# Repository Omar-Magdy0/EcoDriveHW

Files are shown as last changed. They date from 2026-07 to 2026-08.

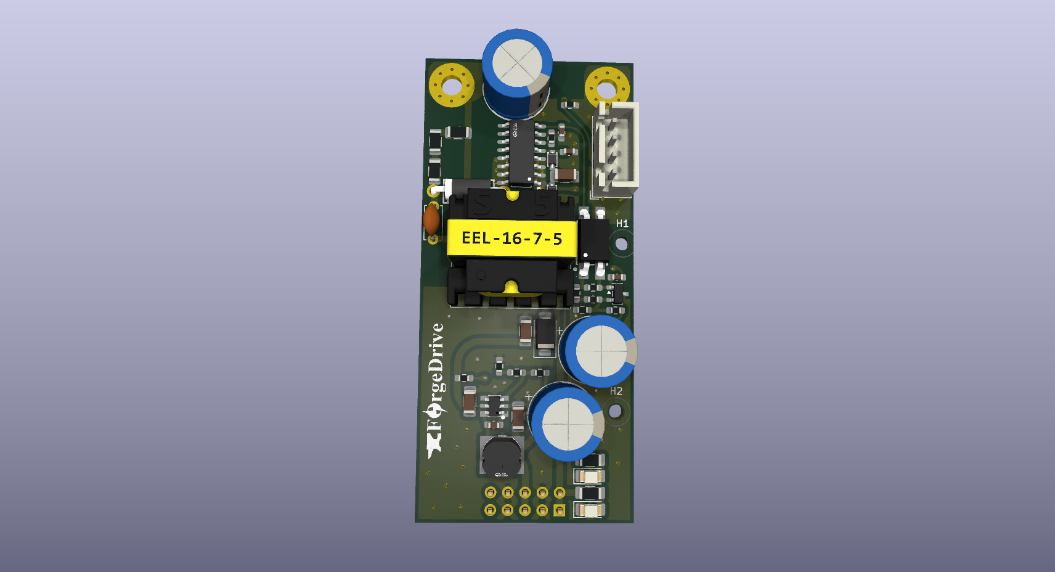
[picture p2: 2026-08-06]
Doc/ForgeX/G0/PSU0.png

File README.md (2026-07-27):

# ForgeDriveHW

_Forged by passionate engineers._

ForgeDrive is an open-source research and development platform for modular, scalable, and industrial-inspired systems.

ForgeDrive is an ecosystem of reusable hardware, firmware, tools, and documentation covering the complete development process—from power electronics and embedded software to simulation, validation, and manufacturing.

The project aims to bridge the gap between academic learning, rapid prototyping, and industrial engineering practices.

---

Vision

ForgeDrive is built around one simple idea:

«Engineering should be understandable, modular, and reusable.»

Every hardware module, software component, and document is designed with long-term maintainability and extensibility in mind.

Whether developing a compact BLDC controller or a complete industrial servo drive, the same design philosophy applies:

- Modular architectures
- Well-defined interfaces
- Thorough documentation
- Reusable building blocks
- Continuous improvement through experimentation

---

##Core Principles

**Modularity**

Each subsystem has a single responsibility.

Examples include:

- Power stages
- Low-voltage distribution
- Communication modules
- Power supplies
- Signal conditioning
- Encoder interfaces
- Processing modules

Modules should be independently testable and reusable across projects.

---

**Scalability**

ForgeDrive is designed to scale across applications.

The same architecture should support:

- Laboratory prototypes
- Educational platforms
- Robotics
- CNC systems
- Industrial automation
- Research projects

---

**Engineering First**

Design decisions are driven by engineering rather than trends.

Topics documented throughout the project include:

- PCB layout
- Power electronics
- Thermal management
- EMC considerations
- Signal integrity
- Embedded software architecture
- Control algorithms
- System reliability

---

**Learning by Building**

ForgeDrive is intended to be as educational as it is practical.

Whenever possible, documentation explains:

- Why a decision was made
- Alternative approaches
- Trade-offs
- Advantages and disadvantages
- Experimental results

The goal is to share engineering knowledge—not only finished hardware.

---

Project Scope

ForgeDrive currently explores technologies including:

Hardware

- PMSM Inverters
- BLDC Controllers
- Three-phase power stages
- PFC converters
- Flyback power supplies
- Low-voltage power distribution
- Encoder interfaces
- Communication modules
- Protection circuitry
- High-speed PCB design

---

Embedded Software

- STM32 Development
- Embedded C/C++
- CMSIS
- Low-Level Drivers
- Real-Time Systems
- Communication Protocols
- Bootloaders
- Firmware Architecture

---

Control

- Field Oriented Control (FOC)
- Space Vector Modulation (SVM)
- Trapezoidal Control
- Current Control
- Position Control
- Speed Control
- Sensorless Algorithms

---

Modeling & Simulation

- MATLAB / Simulink
- Model-Based Design (MBD)
- Plant Modeling
- Controller Design
- System Validation

---

Mechanical

- Enclosures
- Thermal Design
- Mounting Systems
- Mechanical Integration

---

## Documentation

Documentation is considered a first-class component of the project.

Each hardware module includes:

- Board overview
- Bring-up guide
- Revision history
- Manufacturing notes
- Known issues
- Validation results

Shared documentation includes:

- System architecture
- Communication protocols
- Electrical standards
- Design guidelines
- Safety considerations
- Development workflow

---

Hardware revisions are maintained independently while Git preserves complete design history.

---

## Design Philosophy

ForgeDrive emphasizes:

- Single Responsibility Principle (SRP)
- Interface-driven design
- Reusable modules
- Hardware abstraction
- Deterministic behavior
- Debuggability
- Maintainability
- Reliability over unnecessary complexity

---

## Open Source

ForgeDrive is developed in the open.

The repository welcomes:

- Bug reports
- Suggestions
- Design discussions
- Pull requests
- Technical reviews

Constructive engineering feedback is always appreciated.

---

## Roadmap

Some long-term goals include:

- Modular PMSM inverter platform
- Modular PFC stage
- Modular power supplies
- Industrial communication modules
- FPGA acceleration
- Complete documentation
- Hardware validation reports
- Automated testing infrastructure
- Educational design guides

---

## Disclaimer

ForgeDrive contains hardware intended for development, experimentation, and learning.

Many projects involve hazardous voltages, high currents, and high-energy systems.

Always follow appropriate electrical safety practices and verify designs before use in real-world applications.

---

License

This repository is released under the applicable open-source license included in this project.

Please refer to the LICENSE file for details.

---

Acknowledgements

ForgeDrive is built through curiosity, experimentation, continuous learning, and a passion for engineering.

«Forged by passionate engineers.»

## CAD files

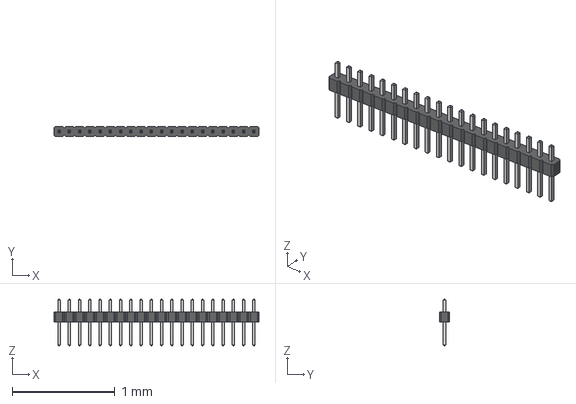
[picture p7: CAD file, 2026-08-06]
ForgeX/BlackDev_G0Basic/LibLocal/header.stp
2.00 x 0.1 x 0.454 mm

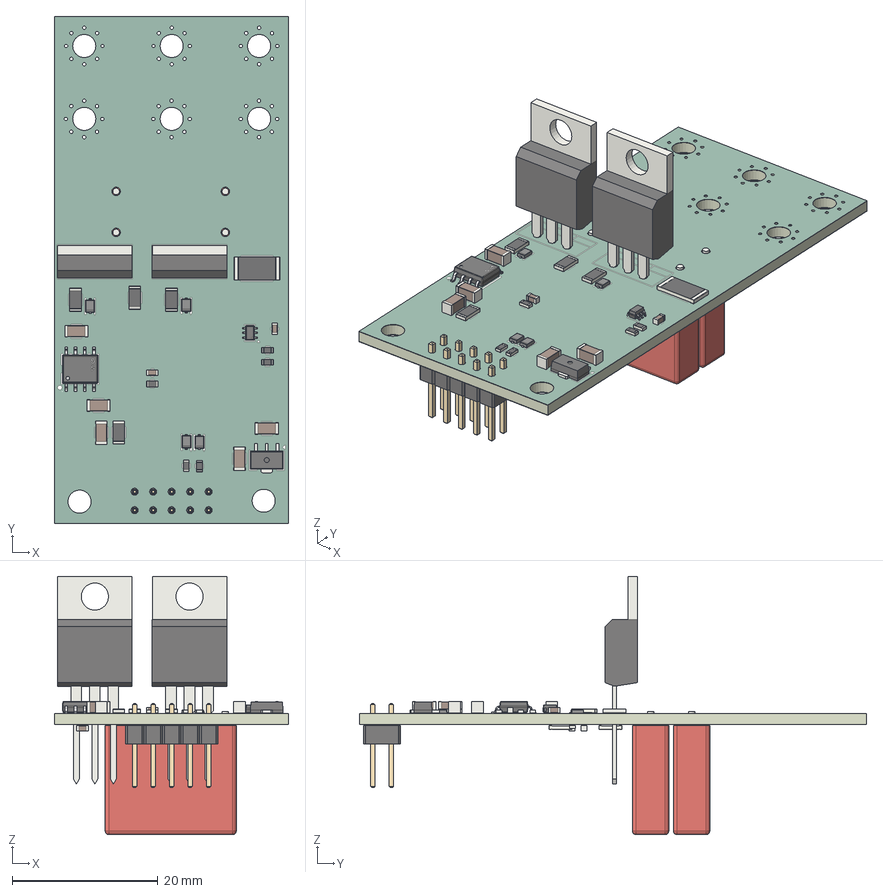
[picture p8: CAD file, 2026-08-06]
ForgeX/HBM_G0VH4C5/revA/Doc/HBM_G0VH4C5.step
32.1 x 69.6 x 35.5 mm
TO-220-3_Vertical x 2
R_0603_1608Metric x 7
C_1206_3216Metric x 5
C_0603_1608Metric x 4
adbeea57-9c39-11ed-93f0-dde97e994e83_part
adbeea58-9c39-11ed-93f0-dde97e994e83_part
adbeea59-9c39-11ed-93f0-dde97e994e83_part
R_2512_6332Metric
R_1206_3216Metric x 6
SO-8_L4.9-W3.9-H1.5-LS5.9-P1.27
SOT-363_SC-70-6
SOD-323_L1.7-W1.3-LS2.5-FD x 4
C_Rect_L180mm_W50mm_P1500mm_FKS3_FKP3 x 2
PinHeader_2x05_P254mm_Vertical
HBM_G0VH4C5_silkscreen x 2
HBM_G0VH4C5_soldermask x 2
HBM_G0VH4C5_PCB

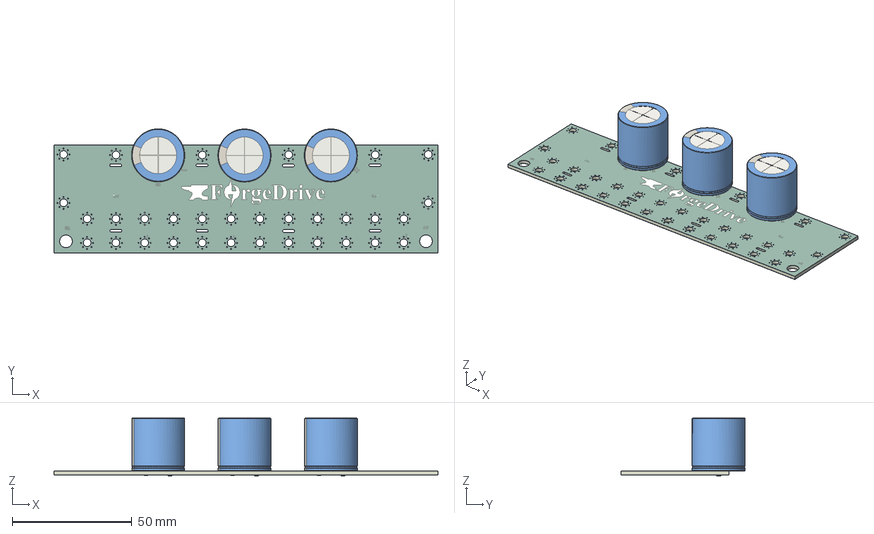
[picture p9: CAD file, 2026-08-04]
ForgeX/PMB_G0S4VH4/revA/Doc/PMB_G0S4VH4.step
160.1 x 51.8 x 24.0 mm
CP_Radial_D220mm_P1000mm_SnapIn x 3
PMB_G0S4VH4_silkscreen
PMB_G0S4VH4_soldermask x 2
PMB_G0S4VH4_PCB

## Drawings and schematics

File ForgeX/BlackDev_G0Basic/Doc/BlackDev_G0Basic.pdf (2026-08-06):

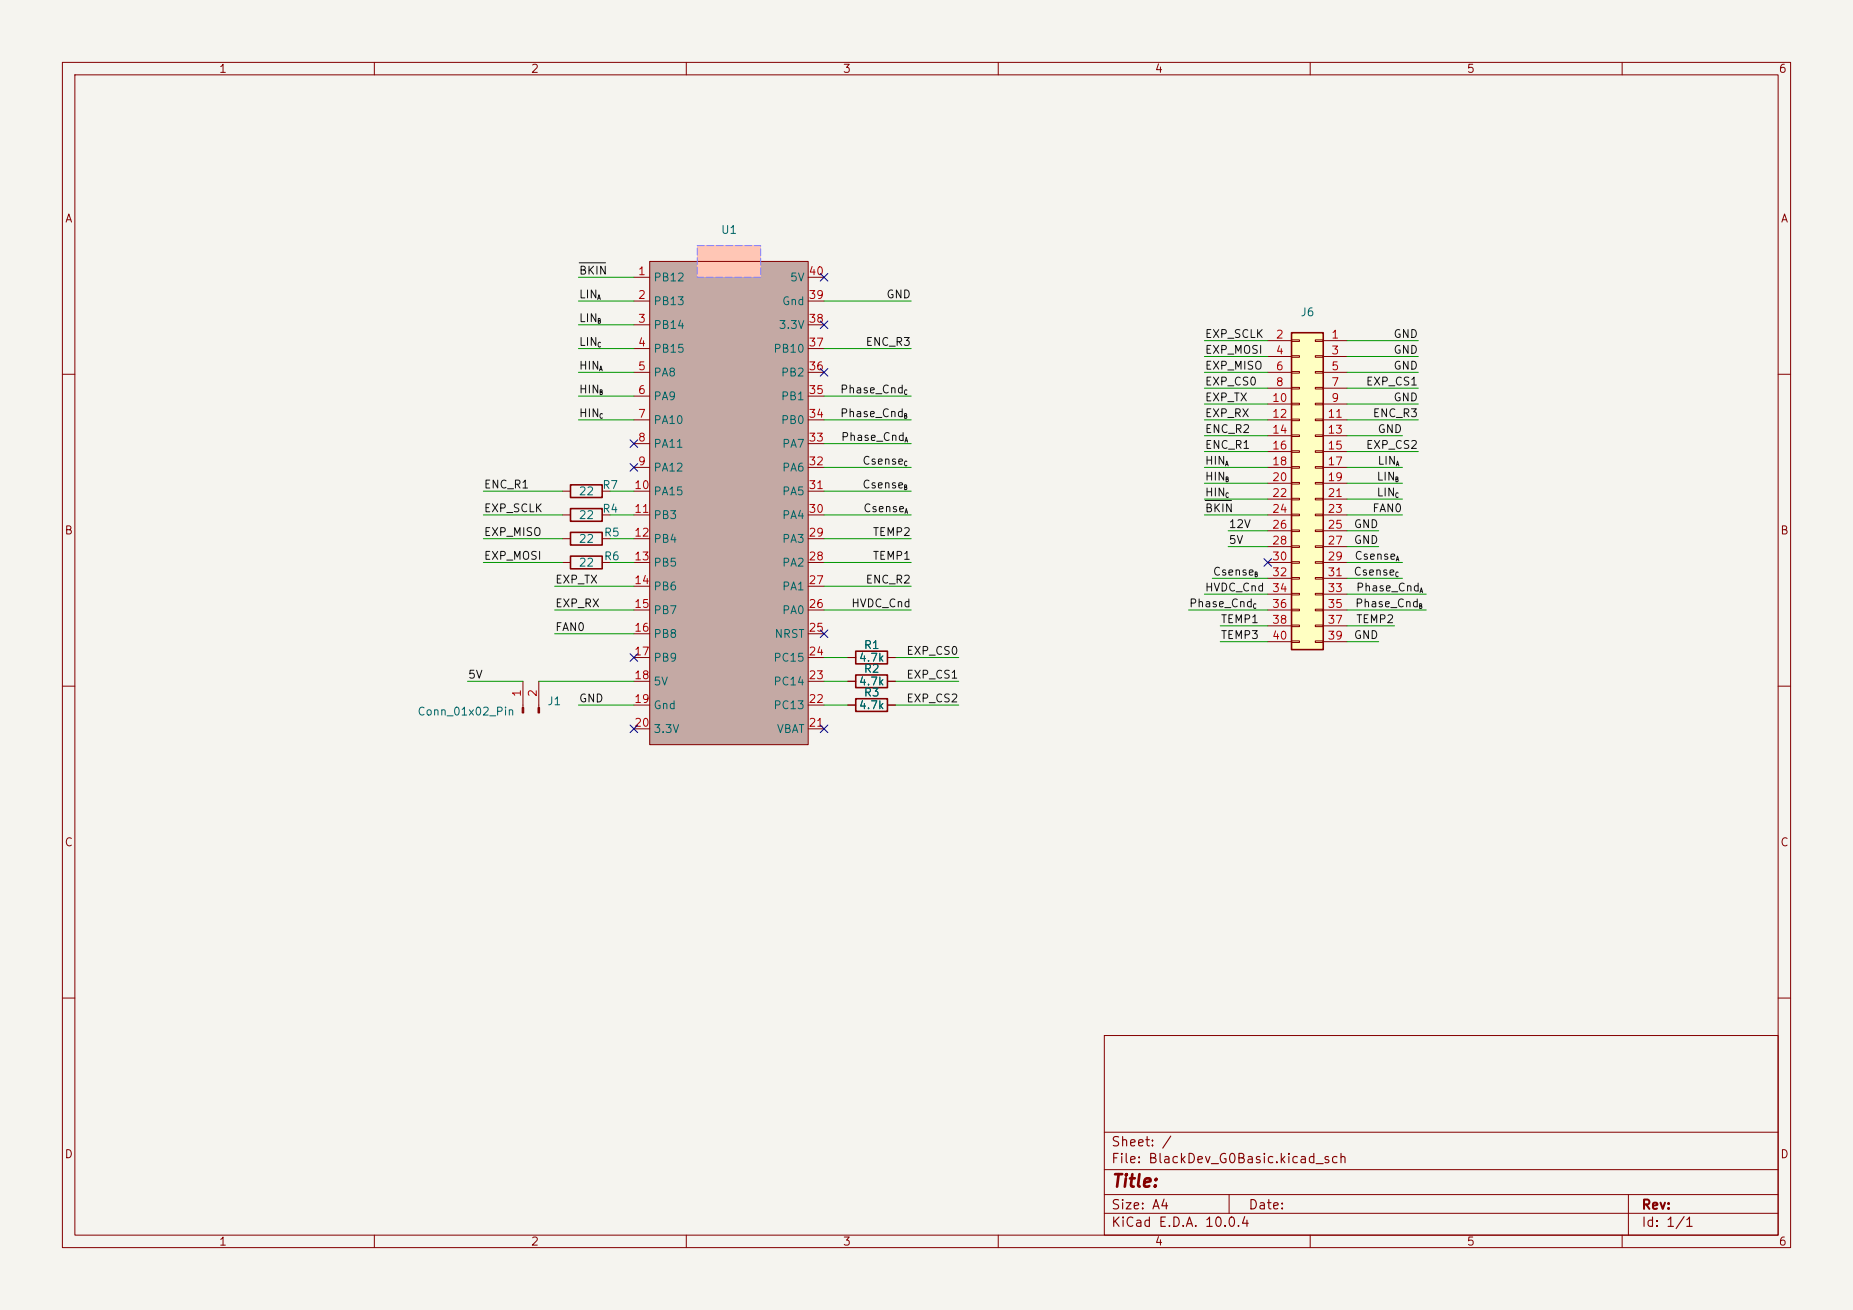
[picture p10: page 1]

Size: A4 | Rev:
KiCad E.D.A. 10.0.4 | Id: 1/1

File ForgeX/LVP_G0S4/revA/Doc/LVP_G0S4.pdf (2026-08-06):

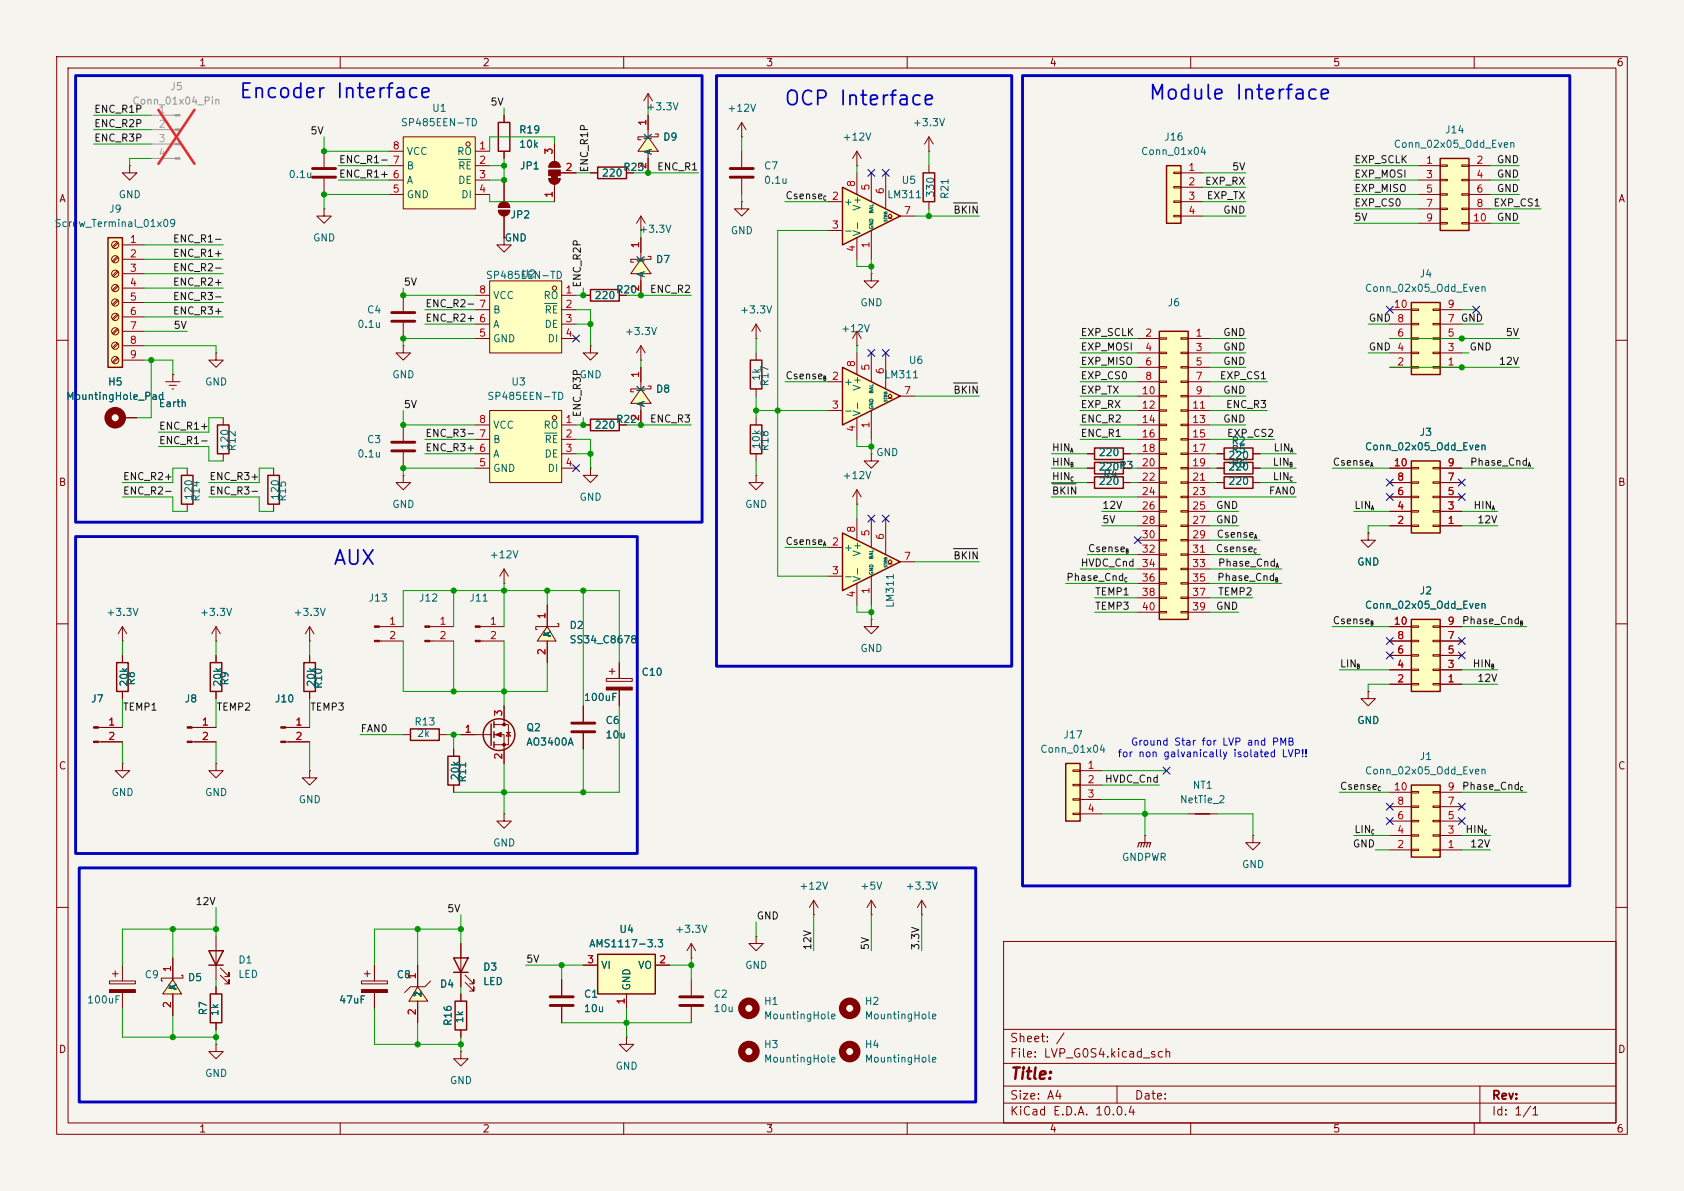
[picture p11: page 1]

for non galvanically isolated LVP!! OCP Interface Encoder Interface

Size: A4 | Rev:
KiCad E.D.A. 10.0.4 | Id: 1/1

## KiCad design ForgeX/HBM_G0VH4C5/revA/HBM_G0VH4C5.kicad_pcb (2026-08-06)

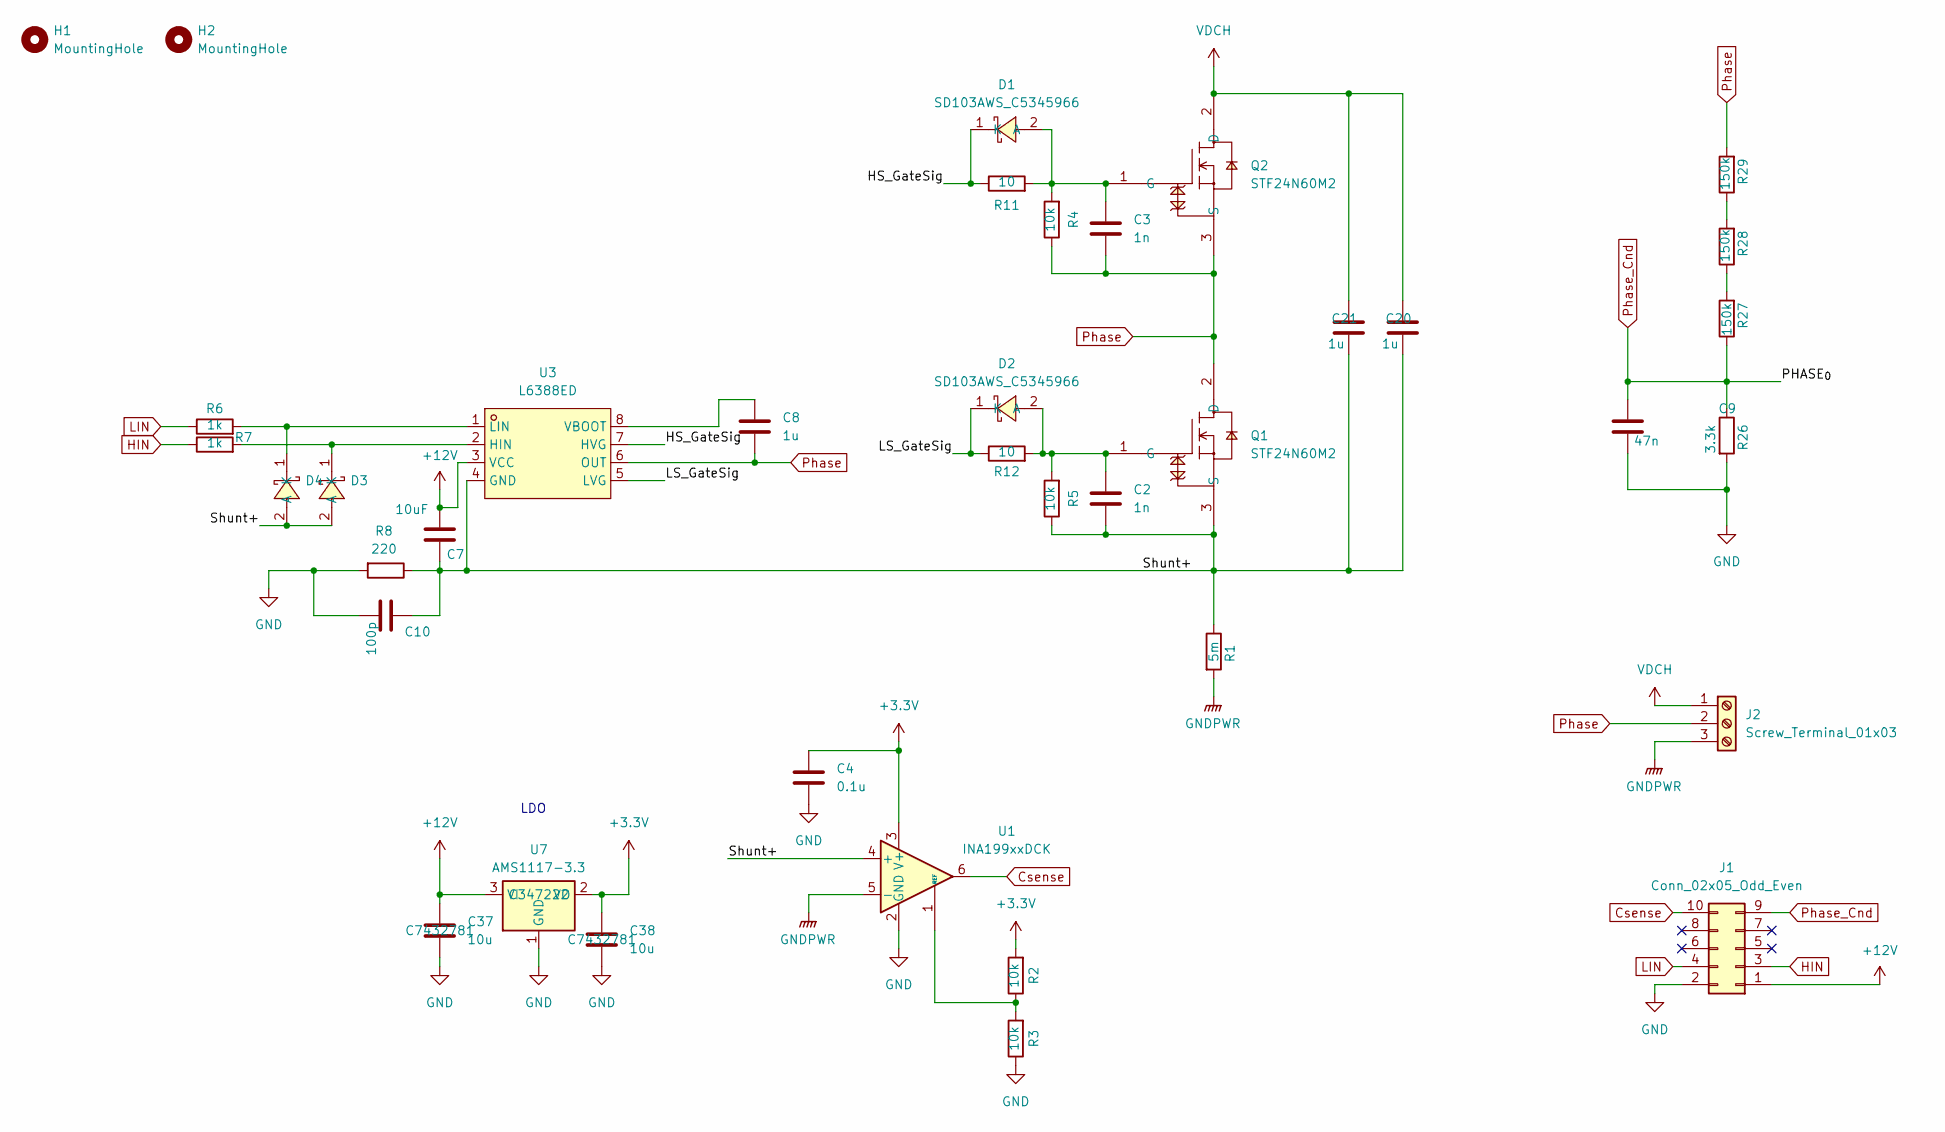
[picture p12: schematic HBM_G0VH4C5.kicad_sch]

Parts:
C2, C3: 1n; C_0603_1608Metric_Pad1.08x0.95mm_HandSolder
C4: 0.1u; C_0603_1608Metric_Pad1.08x0.95mm_HandSolder; LCSC Part C7432781
C7: 10uF; C_1206_3216Metric_Pad1.33x1.80mm_HandSolder
C8: 1u; C_1206_3216Metric_Pad1.33x1.80mm_HandSolder
C9: 47n; C_0603_1608Metric_Pad1.08x0.95mm_HandSolder
C10: 100p; C_1206_3216Metric_Pad1.33x1.80mm_HandSolder
C20, C21: 1u; C_Rect_L18.0mm_W5.0mm_P15.00mm_FKS3_FKP3
C37, C38: 10u; C_1206_3216Metric_Pad1.33x1.80mm_HandSolder; LCSC Part C7432781
D1, D2, D3, D4: SD103AWS_C5345966; SOD-323_L1.7-W1.3-LS2.5-RD; MPN SD103AWS; LCSC Part C5345966
H1, H2: MountingHole; MountingHole_3.2mm_M3_DIN965
J1: Conn_02x05_Odd_Even; PinHeader_2x05_P2.54mm_Vertical
J2: Screw_Terminal_01x03; SPACER_M3_PCONN_2x03
Q1, Q2: STF24N60M2; TO-220-3_Vertical; MPN STF24N60M2; LCSC Part C141847
R1: 5m; R_2512_6332Metric_Pad1.40x3.35mm_HandSolder
R2, R3, R4, R5: 10k; R_0603_1608Metric_Pad0.98x0.95mm_HandSolder
R6, R7: 1k; R_0603_1608Metric_Pad0.98x0.95mm_HandSolder
R8: 220; R_1206_3216Metric_Pad1.30x1.75mm_HandSolder
R11, R12: 10; R_1206_3216Metric_Pad1.30x1.75mm_HandSolder
R26: 3.3k; R_0603_1608Metric_Pad0.98x0.95mm_HandSolder
R27, R28, R29: 150k; R_1206_3216Metric_Pad1.30x1.75mm_HandSolder
U1: INA199xxDCK; SOT-363_SC-70-6
U3: L6388ED; SO-8_L4.9-W3.9-P1.27-LS5.9-BL; MPN L6388ED; LCSC Part C1549313
U7: AMS1117-3.3; SOT-89-3; LCSC Part C347222

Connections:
+3.3V: C4.1, C38.1, R2.2, U1.3 (V+), U7.2 (VO)
+12V: C7.1, C37.1, J1.1, U3.3 (VCC), U7.3 (VI)
/HS_GateSig: D1.1 (K), R11.1, U3.7 (HVG)
/LS_GateSig: D2.1 (K), R12.1, U3.5 (LVG)
/Shunt+: C2.2, C7.2, C10.1, C20.2, C21.2, D3.2 (A), D4.2 (A), Q1.3 (S), R1.1, R5.1, R8.1, U1.4 (+), U3.4 (GND)
Csense: J1.10, U1.6
GND: C4.2, C9.2, C10.2, C37.2, C38.2, J1.2, R3.1, R8.2, R26.2, U1.2 (GND), U7.1 (GND)
GNDPWR: J2.3, R1.2, U1.5 (-)
HIN: J1.3, R7.1
LIN: J1.4, R6.1
unnamed: C3.1, D1.2 (A), Q2.1 (G), R4.2, R11.2
unnamed: C2.1, D2.2 (A), Q1.1 (G), R5.2, R12.2
unnamed: D3.1 (K), R7.2, U3.2 (HIN)
unnamed: D4.1 (K), R6.2, U3.1 (LIN)
unnamed: R27.2, R28.1
unnamed: R28.2, R29.1
unnamed: R2.1, R3.2, U1.1 (REF)
unnamed: C8.1, U3.8 (VBOOT)
Phase: C3.2, C8.2, J2.2, Q1.2 (D), Q2.3 (S), R4.1, R29.2, U3.6 (OUT)
Phase_Cnd: C9.1, J1.9, R26.1, R27.1
VDCH: C20.1, C21.1, J2.1, Q2.2 (D)

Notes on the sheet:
LDO

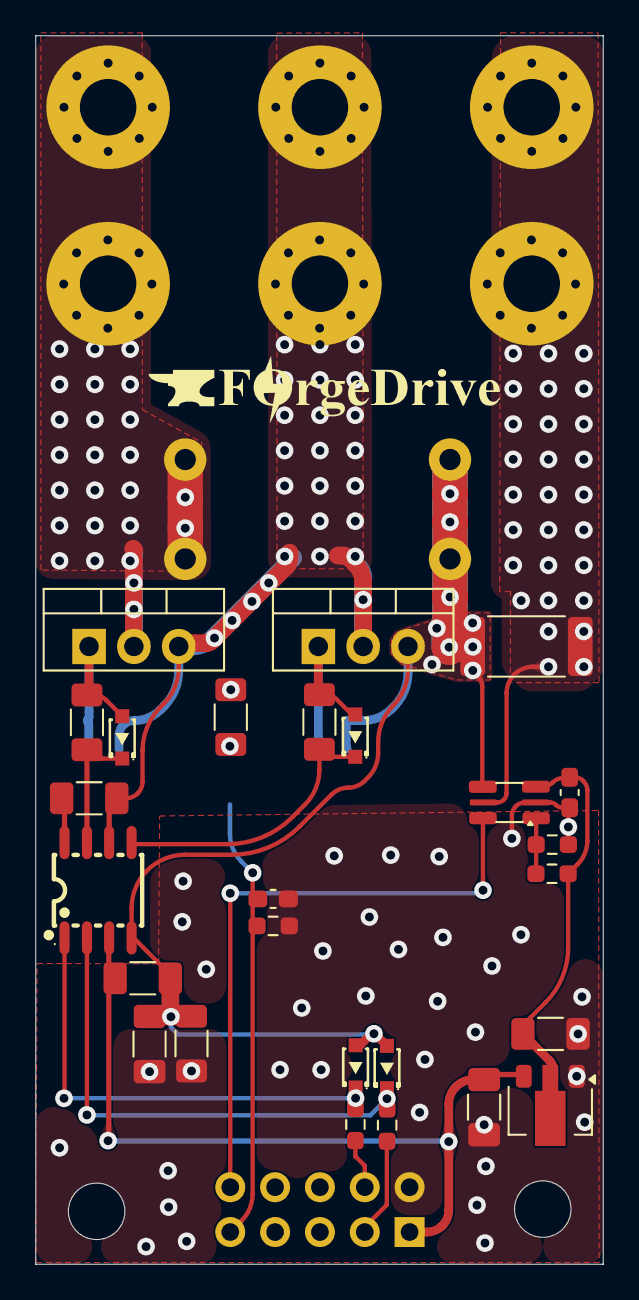
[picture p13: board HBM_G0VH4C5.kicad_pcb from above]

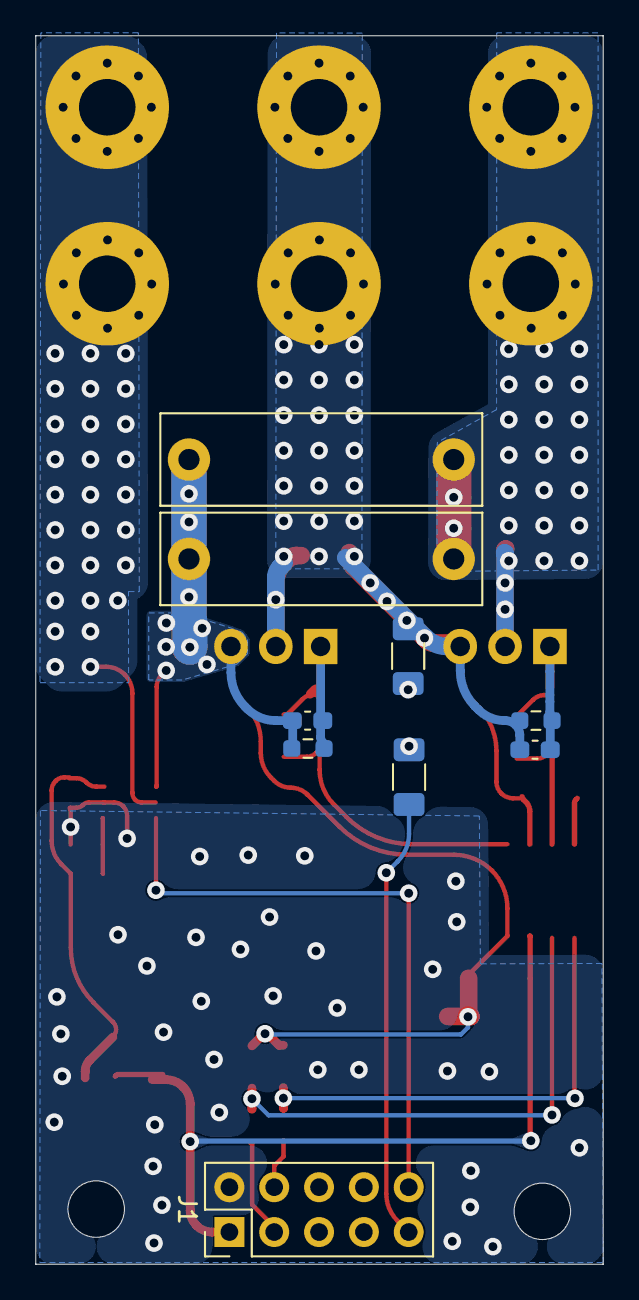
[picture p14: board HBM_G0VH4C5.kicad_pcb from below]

Board: 2 copper layers, 32.2 x 69.6 mm, 38 parts (9 on the bottom side), 21 nets.

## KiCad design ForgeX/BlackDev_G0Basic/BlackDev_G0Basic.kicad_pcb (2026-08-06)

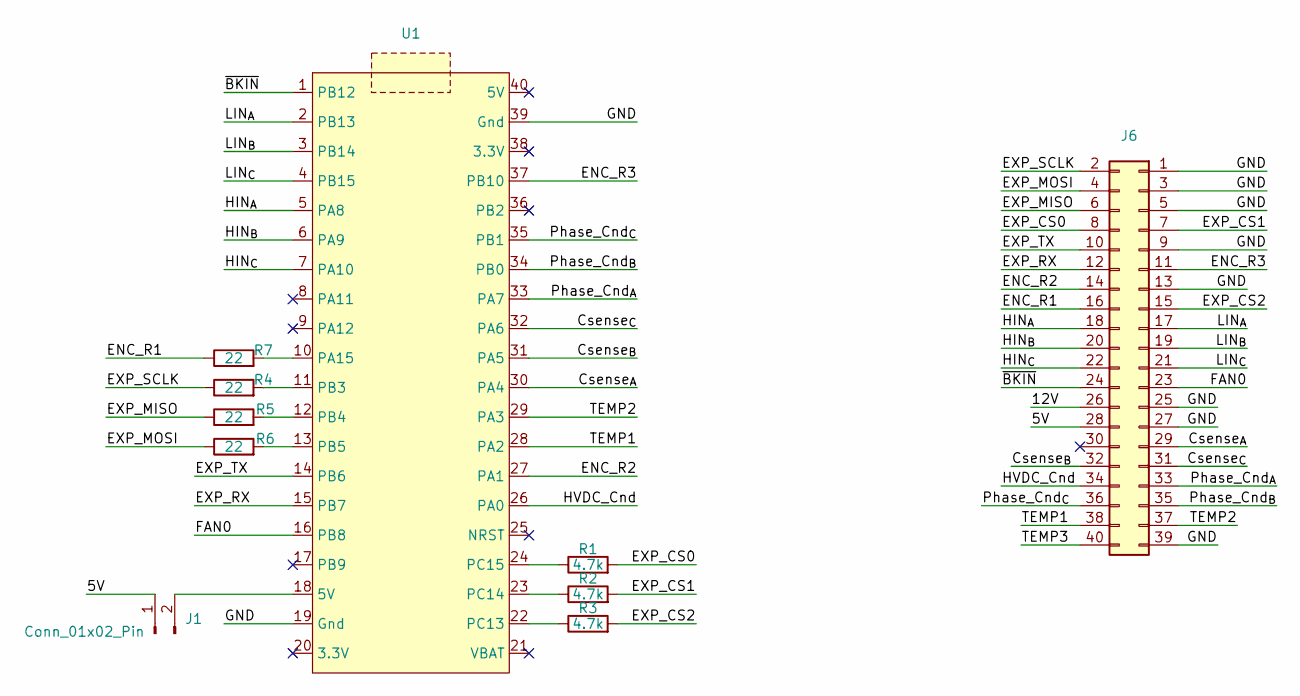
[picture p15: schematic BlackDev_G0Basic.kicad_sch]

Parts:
J1: Conn_01x02_Pin; PinHeader_1x02_P2.54mm_Vertical
J6: Conn_02x20_Odd_Even; PinHeader_2x20_P2.54mm_Vertical
R1, R2, R3: 4.7k; R_0603_1608Metric_Pad0.98x0.95mm_HandSolder
R4, R5, R6, R7: 22; R_0603_1608Metric_Pad0.98x0.95mm_HandSolder
U1: Stm32BlackPill

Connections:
/5V: J1.1, J6.28
/12V: J6.26
/Csense_{A}: J6.29, U1.30 (PA4)
/Csense_{B}: J6.32, U1.31 (PA5)
/Csense_{C}: J6.31, U1.32 (PA6)
/ENC_R1: J6.16, R7.1
/ENC_R2: J6.14, U1.27 (PA1)
/ENC_R3: J6.11, U1.37 (PB10)
/EXP_CS0: J6.8, R1.2
/EXP_CS1: J6.7, R2.2
/EXP_CS2: J6.15, R3.2
/EXP_MISO: J6.6, R5.1
/EXP_MOSI: J6.4, R6.1
/EXP_RX: J6.12, U1.15 (PB7)
/EXP_SCLK: J6.2, R4.1
/EXP_TX: J6.10, U1.14 (PB6)
/FAN0: J6.23, U1.16 (PB8)
/GND: J6.1, J6.3, J6.5, J6.9, J6.13, J6.25, J6.27, J6.39, U1.19 (Gnd), U1.39 (Gnd)
/HIN_{A}: J6.18, U1.5 (PA8)
/HIN_{B}: J6.20, U1.6 (PA9)
/HIN_{C}: J6.22, U1.7 (PA10)
/HVDC_Cnd: J6.34, U1.26 (PA0)
/LIN_{A}: J6.17, U1.2 (PB13)
/LIN_{B}: J6.19, U1.3 (PB14)
/LIN_{C}: J6.21, U1.4 (PB15)
/Phase_Cnd_{A}: J6.33, U1.33 (PA7)
/Phase_Cnd_{B}: J6.35, U1.34 (PB0)
/Phase_Cnd_{C}: J6.36, U1.35 (PB1)
/TEMP1: J6.38, U1.28 (PA2)
/TEMP2: J6.37, U1.29 (PA3)
/TEMP3: J6.40
/~BKIN: J6.24, U1.1 (PB12)
unnamed: J1.2, U1.18 (5V)
unnamed: R7.2, U1.10 (PA15)
unnamed: R4.2, U1.11 (PB3)
unnamed: R5.2, U1.12 (PB4)
unnamed: R6.2, U1.13 (PB5)
unnamed: R3.1, U1.22 (PC13)
unnamed: R2.1, U1.23 (PC14)
unnamed: R1.1, U1.24 (PC15)

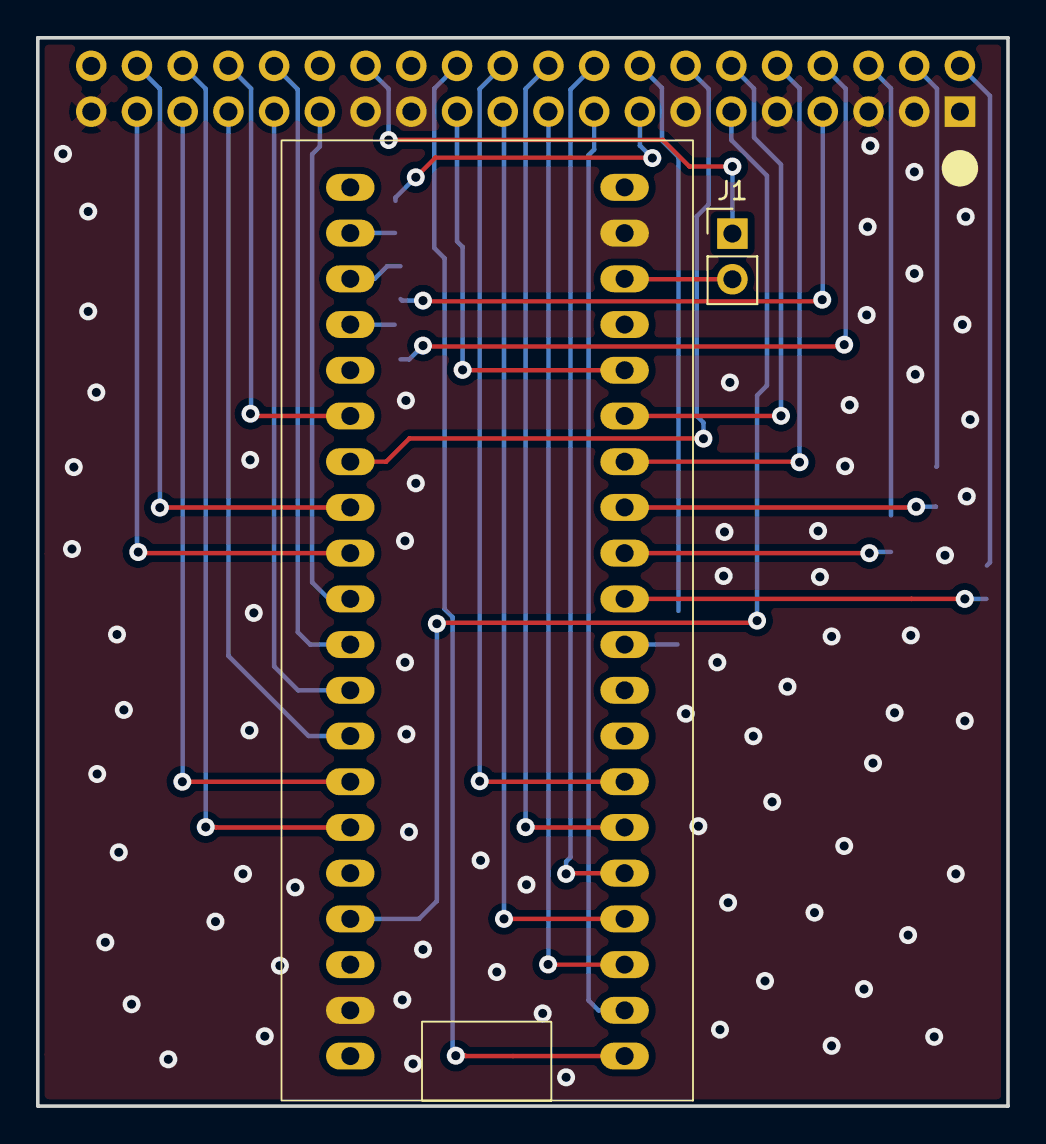
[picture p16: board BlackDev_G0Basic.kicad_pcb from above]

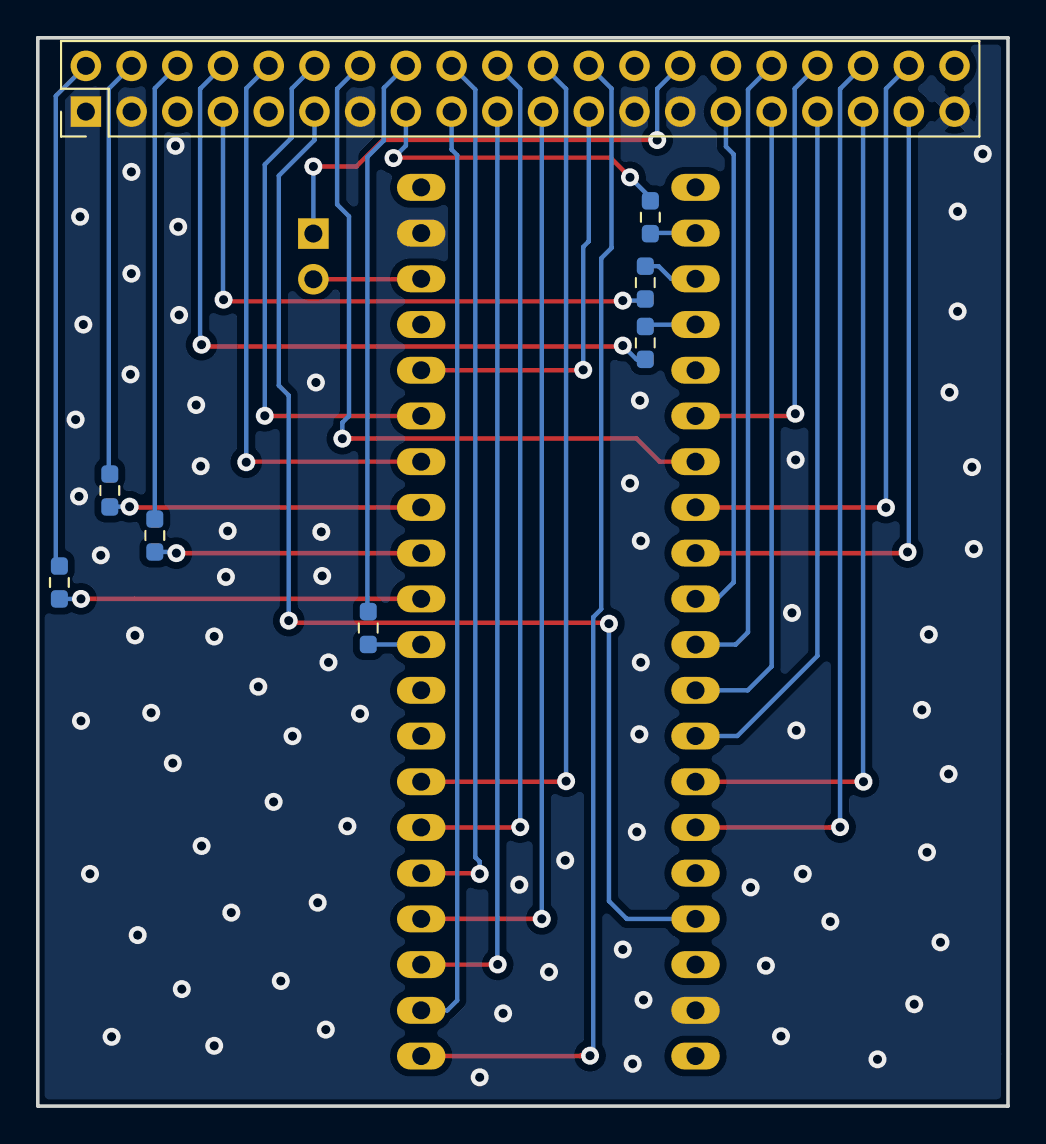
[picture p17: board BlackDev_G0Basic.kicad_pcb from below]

Board: 2 copper layers, 53.9 x 59.4 mm, 10 parts (8 on the bottom side), 38 nets.

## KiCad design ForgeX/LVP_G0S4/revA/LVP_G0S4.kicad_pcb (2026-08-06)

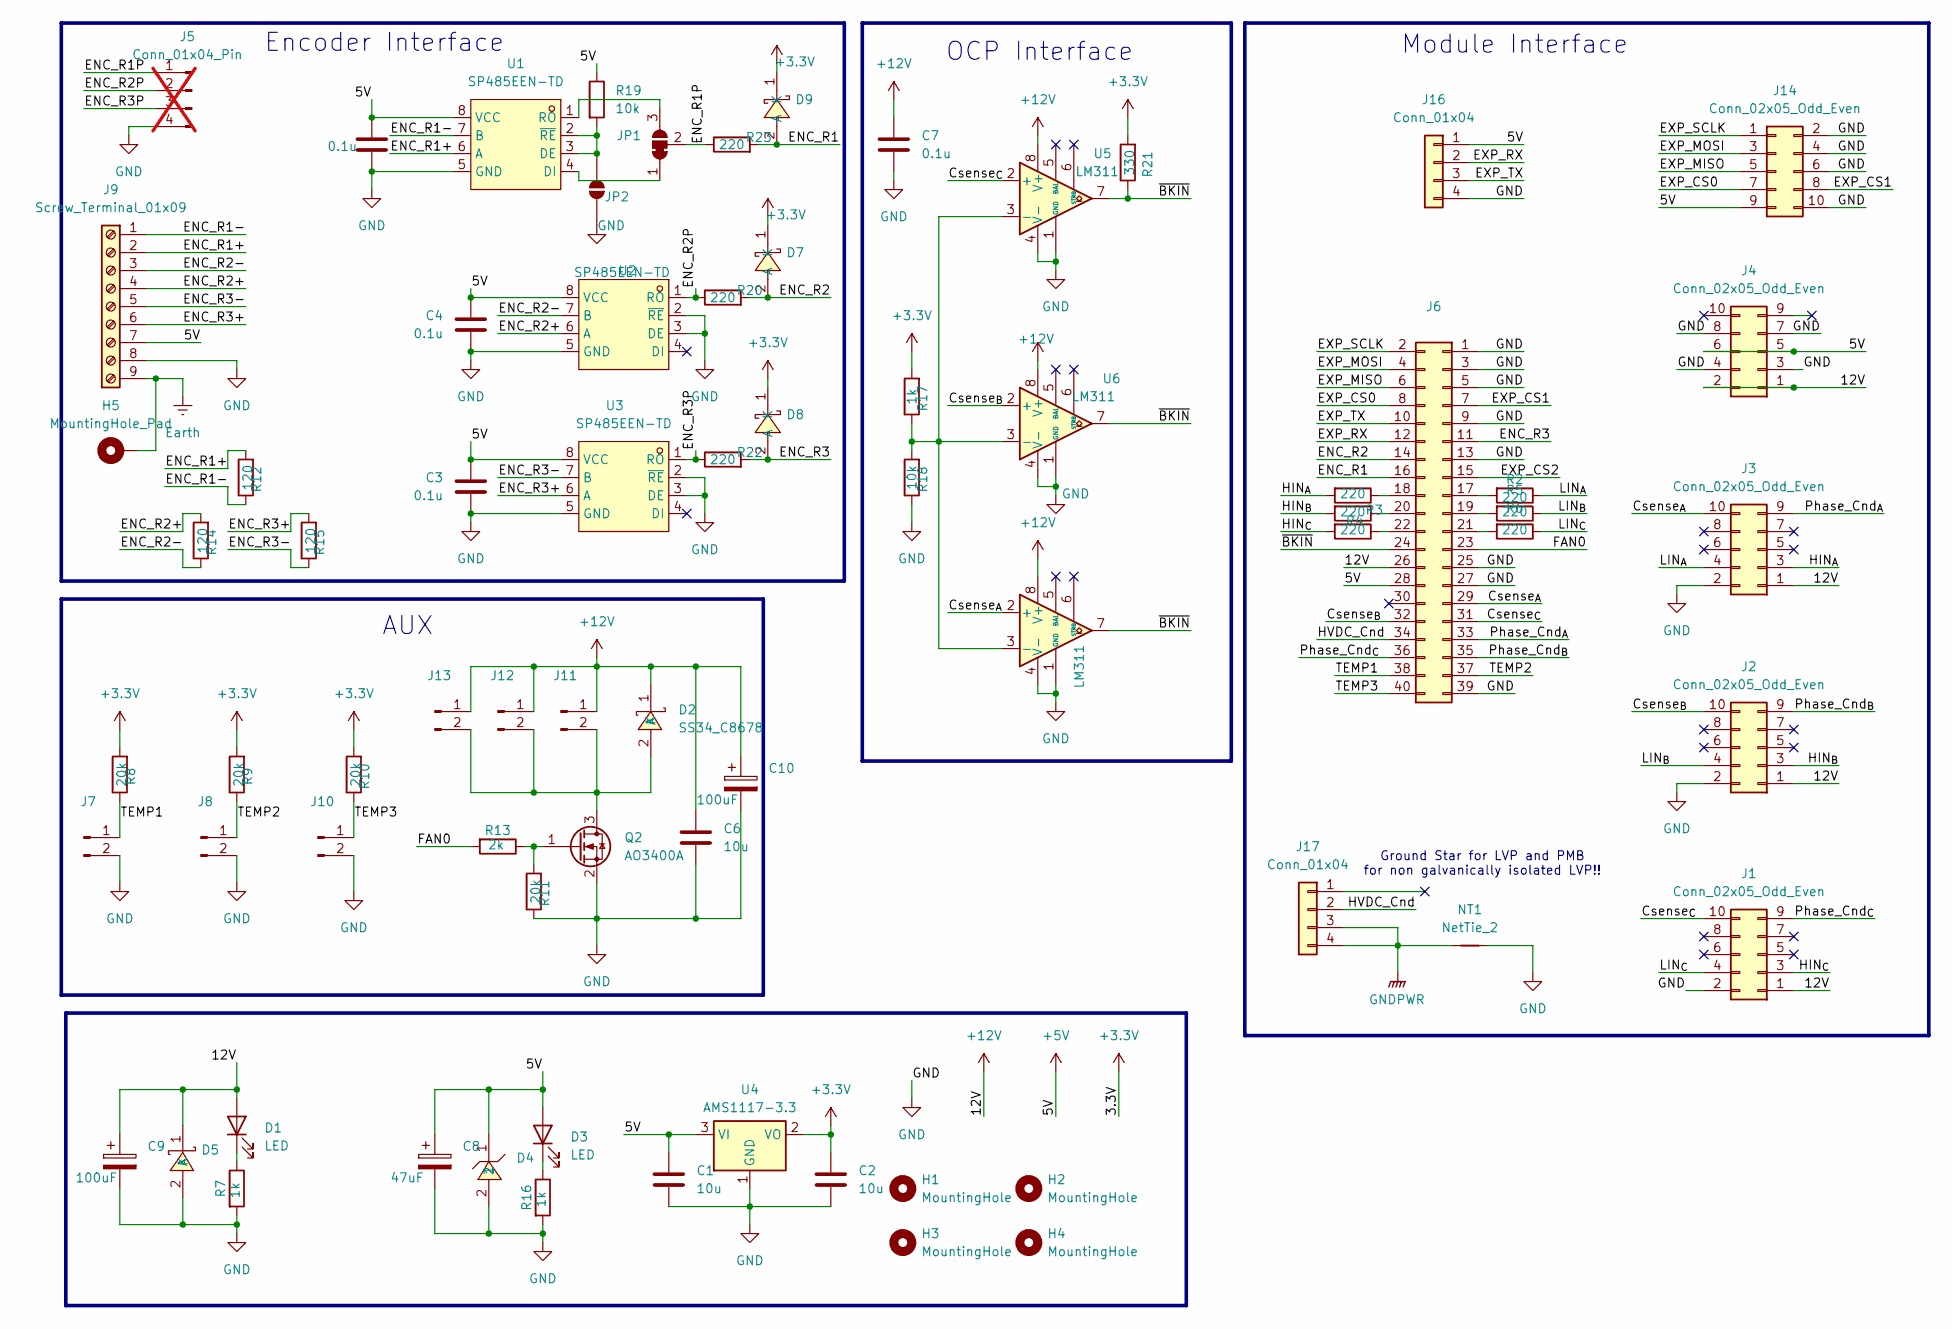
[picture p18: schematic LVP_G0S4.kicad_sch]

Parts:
C1, C2, C6: 10u; C_1206_3216Metric_Pad1.33x1.80mm_HandSolder
C3, C4, C11: 0.1u; C_0603_1608Metric_Pad1.08x0.95mm_HandSolder
C7: 0.1u; C_1206_3216Metric_Pad1.33x1.80mm_HandSolder
C8: 47uF; CP_Elec_5x5.4
C9, C10: 100uF; CP_Elec_8x6.5
D1, D3: LED; LED_0603_1608Metric
D2: SS34_C8678; SMA_L4.3-W2.6-LS5.2-RD; MPN SS34; LCSC Part C8678
D4: SMBJ5.0A_C83333; SMB_L4.6-W3.6-LS5.3-RD; MPN SMBJ5.0A; LCSC Part C83333
D5: SMBJ12A_C151251; SMB_L4.6-W3.6-LS5.3-RD; MPN SMBJ12A; LCSC Part C151251
D7, D8, D9: SD103AWS_C5345966; SOD-323_L1.7-W1.3-LS2.5-RD; MPN SD103AWS; LCSC Part C5345966
H1, H2, H3, H4: MountingHole; MountingHole_3.2mm_M3_DIN965
H5: MountingHole_Pad; MountingHole_3.2mm_M3_Pad_Via
J1, J2, J3, J4: Conn_02x05_Odd_Even; PinSocket_2x05_P2.54mm_Vertical
J5: Conn_01x04_Pin; PinHeader_1x04_P1.27mm_Vertical_SMD_Pin1Right; not fitted
J6: Conn_02x20_Odd_Even; PinSocket_2x20_P2.54mm_Vertical
J7, J8, J10, J11, J12, J13: Conn_01x02_Pin; JST_XH_B2B-XH-A_1x02_P2.50mm_Vertical
J9: Screw_Terminal_01x09; JST_XH_B9B-XH-A_1x09_P2.50mm_Vertical
J14: Conn_02x05_Odd_Even; IDC-Header_2x05_P2.54mm_Vertical
J16: Conn_01x04; PinSocket_1x04_P2.54mm_Vertical
J17: Conn_01x04; JST_XH_B4B-XH-A_1x04_P2.50mm_Vertical
JP1: SolderJumper_3_Bridged12; SolderJumper-3_P1.3mm_Bridged12_RoundedPad1.0x1.5mm
JP2: SolderJumper_2_Open; SolderJumper-2_P1.3mm_Open_TrianglePad1.0x1.5mm
NT1: NetTie_2; ground_tie
Q2: AO3400A; SOT-23
R1, R2, R3, R4, R5, R6, R20, R22, R23: 220; R_0603_1608Metric_Pad0.98x0.95mm_HandSolder
R7, R16, R17: 1k; R_0603_1608Metric_Pad0.98x0.95mm_HandSolder
R8, R9, R10, R11: 20k; R_1206_3216Metric_Pad1.30x1.75mm_HandSolder
R12, R14, R15: 120; R_1206_3216Metric_Pad1.30x1.75mm_HandSolder
R13: 2k; R_1206_3216Metric_Pad1.30x1.75mm_HandSolder
R18, R19: 10k; R_0603_1608Metric_Pad0.98x0.95mm_HandSolder
R21: 330; R_0603_1608Metric_Pad0.98x0.95mm_HandSolder
U1, U2, U3: SP485EEN-TD; SOIC-8_L4.9-W3.9-P1.27-LS6.0-BL; MPN SP485EEN-TD; LCSC Part C41369800
U4: AMS1117-3.3; SOT-89-3
U5, U6, U7: LM311; SOIC-8_3.9x4.9mm_P1.27mm

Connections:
+3.3V: C2.1, D7.1 (K), D8.1 (K), D9.1 (K), R8.2, R9.2, R10.2, R17.2, R21.2, U4.2 (VO)
+5V: C1.1, C3.1, C4.1, C8.1, C11.1, D3.2 (A), D4.1, J4.5, J4.6, J6.28, J9.7, J14.9, J16.1, R19.1, U1.8 (VCC), U2.8 (VCC), U3.8 (VCC), U4.3 (VI)
+12V: C6.1, C7.1, C9.1, C10.1, D1.2 (A), D2.1 (K), D5.1 (K), J1.1, J2.1, J3.1, J4.1, J4.2, J6.26, J11.1, J12.1, J13.1, U5.8 (V+), U6.8 (V+), U7.8 (V+)
/Csense_{A}: J3.10, J6.29, U7.2 (+)
/Csense_{B}: J2.10, J6.32, U6.2 (+)
/Csense_{C}: J1.10, J6.31, U5.2 (+)
/ENC_R1: D9.2 (A), J6.16, R23.2
/ENC_R1+: J9.2, R12.2, U1.6 (A)
/ENC_R1-: J9.1, R12.1, U1.7 (B)
/ENC_R1P: J5.1, JP1.2 (C), R23.1
/ENC_R2: D7.2 (A), J6.14, R20.2
/ENC_R2+: J9.4, R14.2, U2.6 (A)
/ENC_R2-: J9.3, R14.1, U2.7 (B)
/ENC_R2P: J5.2, R20.1, U2.1 (RO)
/ENC_R3: D8.2 (A), J6.11, R22.2
/ENC_R3+: J9.6, R15.2, U3.6 (A)
/ENC_R3-: J9.5, R15.1, U3.7 (B)
/ENC_R3P: J5.3, R22.1, U3.1 (RO)
/EXP_CS0: J6.8, J14.7
/EXP_CS1: J6.7, J14.8
/EXP_CS2: J6.15
/EXP_MISO: J6.6, J14.5
/EXP_MOSI: J6.4, J14.3
/EXP_RX: J6.12, J16.2
/EXP_SCLK: J6.2, J14.1
/EXP_TX: J6.10, J16.3
/FAN0: J6.23, R13.2
/HIN_{A}: J3.3, R1.2
/HIN_{B}: J2.3, R3.2
/HIN_{C}: J1.3, R4.2
/HVDC_Cnd: J6.34, J17.2
/LIN_{A}: J3.4, R2.1
/LIN_{B}: J2.4, R5.1
/LIN_{C}: J1.4, R6.1
/Phase_Cnd_{A}: J3.9, J6.33
/Phase_Cnd_{B}: J2.9, J6.35
/Phase_Cnd_{C}: J1.9, J6.36
/TEMP1: J6.38, J7.1, R8.1
/TEMP2: J6.37, J8.1, R9.1
/TEMP3: J6.40, J10.1, R10.1
/~BKIN: J6.24, R21.1, U5.7, U6.7, U7.7
Earth: H5.1 (1_1), J9.9
GND: C1.2, C2.2, C3.2, C4.2, C6.2, C7.2, C8.2, C9.2, C10.2, C11.2, D4.2, D5.2 (A), J1.2, J2.2, J3.2, J4.3, J4.4, J4.7, J4.8, J5.4, J6.1, J6.3, J6.5, J6.9, J6.13, J6.25, J6.27, J6.39, J7.2, J8.2, J9.8, J10.2, J14.2, J14.4, J14.6, J14.10, J16.4, JP2.2 (B), NT1.2, Q2.2 (S), R7.2, R11.1, R16.2, R18.1, U1.5 (GND), U2.2 (~RE), U2.3 (DE), U2.5 (GND), U3.2 (~RE), U3.3 (DE), U3.5 (GND), U4.1 (GND), U5.1 (GND), U5.4 (V-), U6.1 (GND), U6.4 (V-), U7.1 (GND), U7.4 (V-)
GNDPWR: J17.3, J17.4, NT1.1
unnamed: D1.1 (K), R7.1
unnamed: D2.2 (A), J11.2, J12.2, J13.2, Q2.3 (D)
unnamed: D3.1 (K), R16.1
unnamed: J6.17, R2.2
unnamed: J6.18, R1.1
unnamed: J6.19, R5.2
unnamed: J6.20, R3.1
unnamed: J6.21, R6.2
unnamed: J6.22, R4.1
unnamed: JP1.1 (A), U1.4 (DI)
unnamed: JP1.3 (B), U1.1 (RO)
unnamed: JP2.1 (A), R19.2, U1.2 (~RE), U1.3 (DE)
unnamed: Q2.1 (G), R11.2, R13.1
unnamed: R17.1, R18.2, U5.3 (-), U6.3 (-), U7.3 (-)

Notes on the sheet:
OCP Interface
Ground Star for LVP and PMB for non galvanically isolated LVP!!
AUX
Encoder Interface
Module Interface

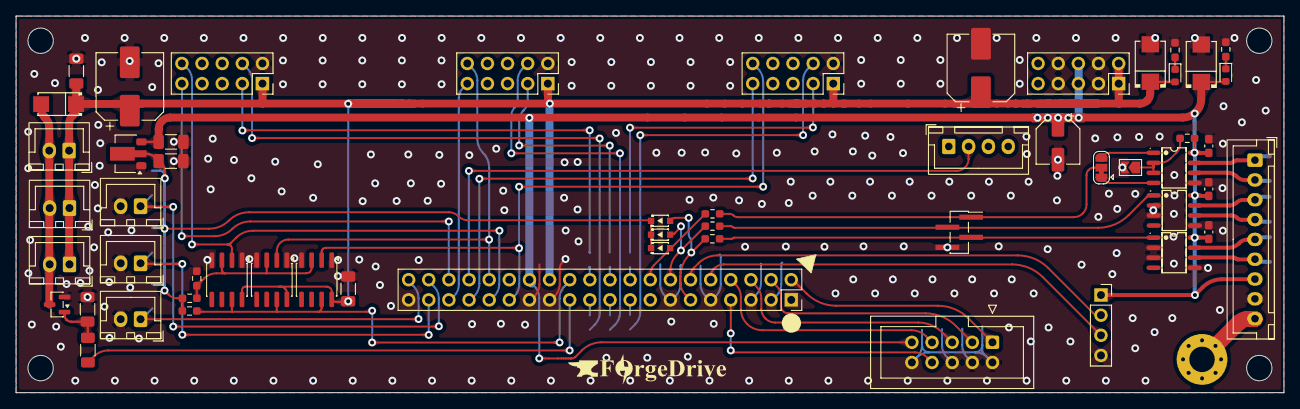
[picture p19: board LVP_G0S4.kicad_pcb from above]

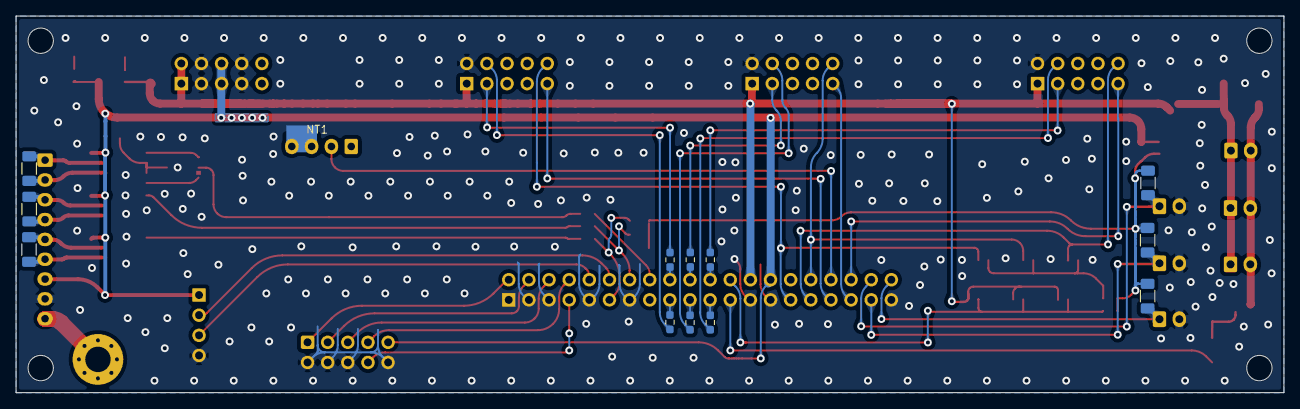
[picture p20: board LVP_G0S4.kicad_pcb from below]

Board: 2 copper layers, 159.9 x 47.5 mm, 73 parts (13 on the bottom side), 57 nets.

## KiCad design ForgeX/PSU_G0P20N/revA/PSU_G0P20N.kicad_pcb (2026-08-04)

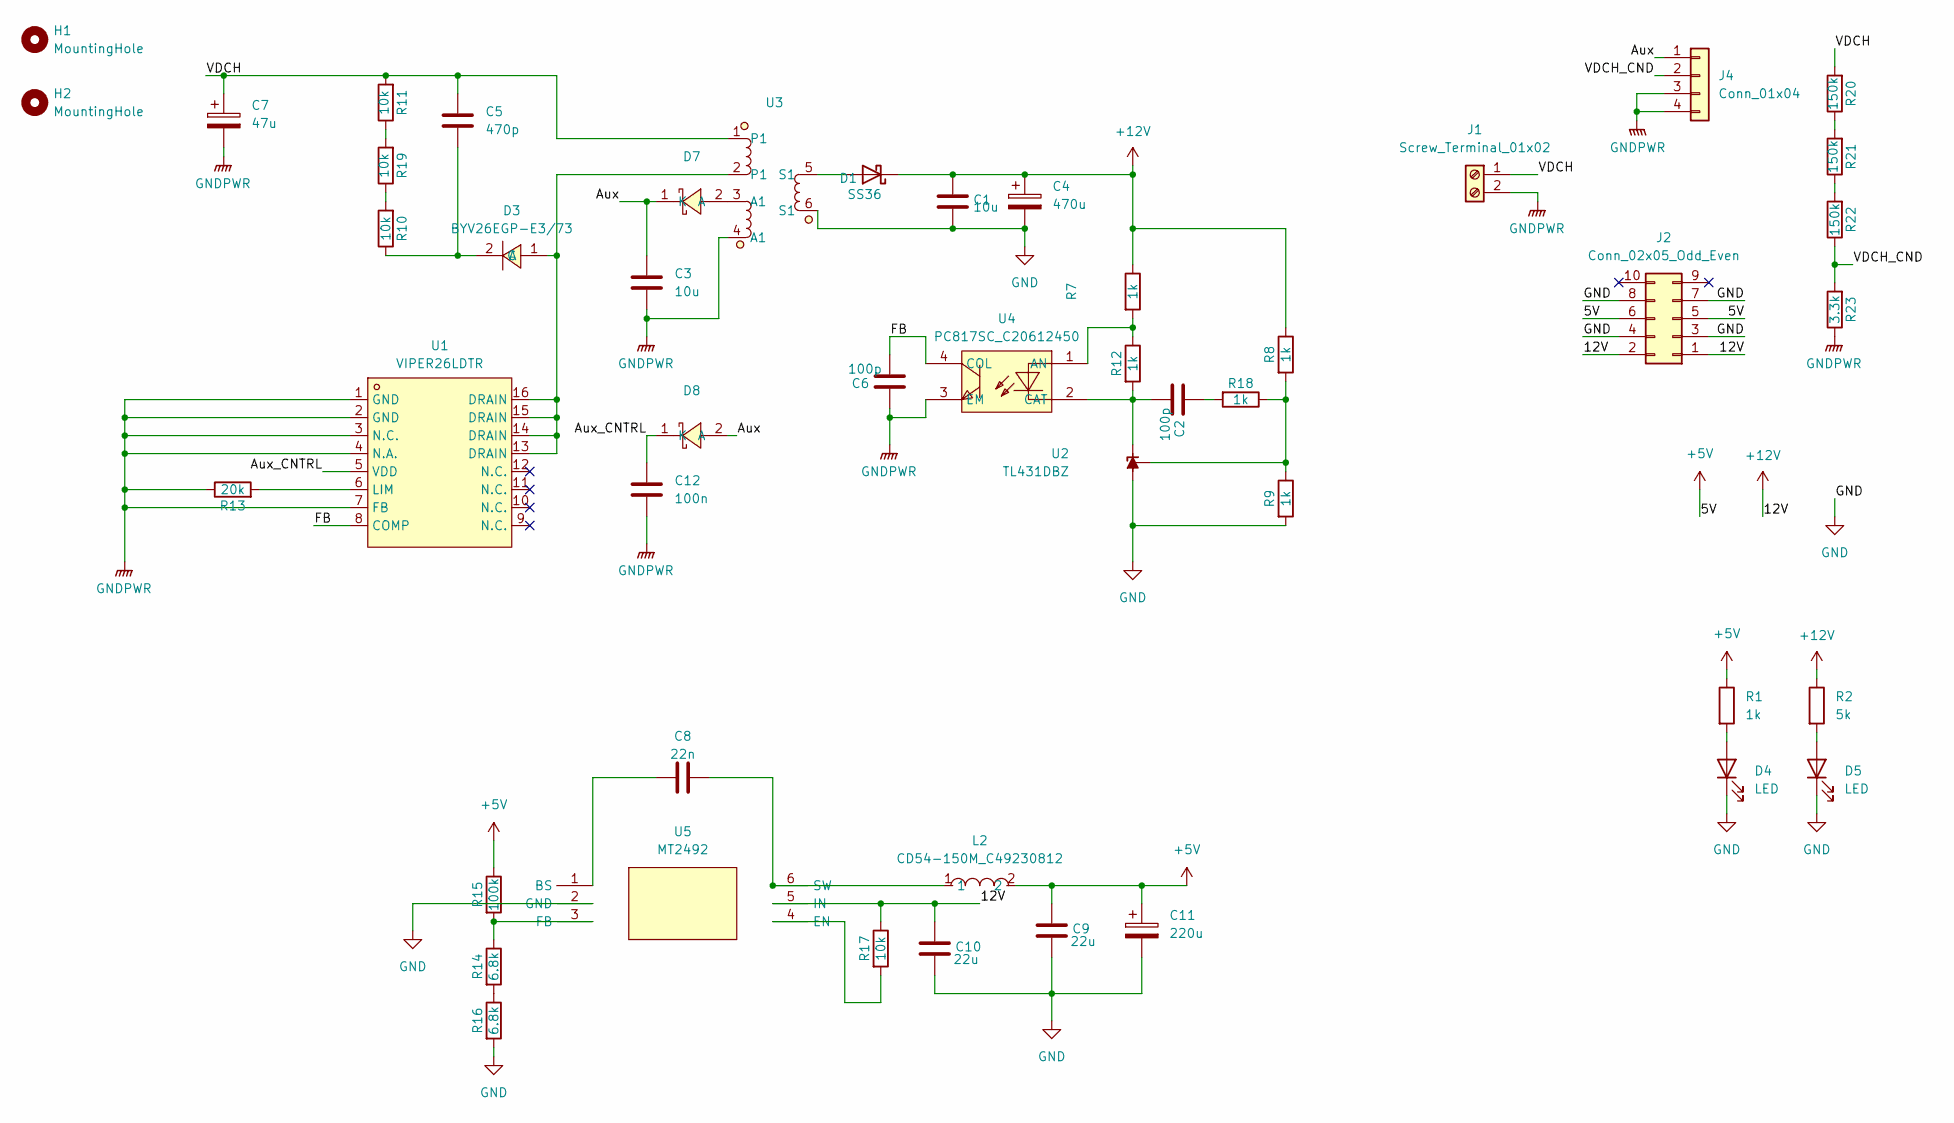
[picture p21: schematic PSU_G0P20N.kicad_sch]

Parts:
C1, C3: 10u; C_1206_3216Metric_Pad1.33x1.80mm_HandSolder
C2, C6: 100p; C_0603_1608Metric_Pad1.08x0.95mm_HandSolder
C4: 470u; CP_Radial_D10.0mm_P5.00mm
C5: 470p; C_Disc_D5.0mm_W2.5mm_P5.00mm
C7: 47u; CP_Radial_D10.0mm_P7.50mm
C8: 22n; C_0603_1608Metric_Pad1.08x0.95mm_HandSolder
C9, C10: 22u; C_1206_3216Metric_Pad1.33x1.80mm_HandSolder
C11: 220u; CP_Radial_D10.0mm_P5.00mm
C12: 100n; C_0603_1608Metric_Pad1.08x0.95mm_HandSolder
D1: SS36; D_SMA
D3: BYV26EGP-E3/73; DO-15_BD3.1-L6.7-P10.70-D0.9-FD; MPN BYV26EGP-E3/73; LCSC Part C15074
D4, D5: LED; LED_1206_3216Metric_Pad1.42x1.75mm_HandSolder
D7, D8: SD103AWS_C5345966; SOD-323_L1.7-W1.3-LS2.5-RD; MPN SD103AWS; LCSC Part C5345966
H1, H2: MountingHole; MountingHole_2.1mm
J1: Screw_Terminal_01x02; SPACER_M3_PCONN_PSU
J2: Conn_02x05_Odd_Even; PinHeader_2x05_P2.54mm_Vertical
J4: Conn_01x04; JST_XH_B4B-XH-A_1x04_P2.50mm_Vertical
L2: CD54-150M_C49230812; IND-SMD_L5.8-W5.2_CD54; MPN CD54-150M; LCSC Part C49230812
R1: 1k; R_1206_3216Metric_Pad1.30x1.75mm_HandSolder
R2: 5k; R_1206_3216Metric_Pad1.30x1.75mm_HandSolder
R7, R8, R9, R12, R18: 1k; R_0603_1608Metric_Pad0.98x0.95mm_HandSolder
R10, R11, R19: 10k; R_1206_3216Metric
R13: 20k; R_0603_1608Metric_Pad0.98x0.95mm_HandSolder
R14, R16: 6.8k; R_0603_1608Metric_Pad0.98x0.95mm_HandSolder
R15: 100k; R_0603_1608Metric_Pad0.98x0.95mm_HandSolder
R17: 10k; R_0603_1608Metric_Pad0.98x0.95mm_HandSolder
R20, R21, R22: 150k; R_1206_3216Metric
R23: 3.3k; R_0603_1608Metric_Pad0.98x0.95mm_HandSolder
U1: VIPER26LDTR; SOIC-16_L9.9-W3.9-P1.27-LS6.0-BL; MPN VIPER26LDTR; LCSC Part C134483
U2: TL431DBZ; SOT-23
U3: E16 Trans
U4: PC817SC_C20612450; OPTO-SMD-4_L4.6-W6.5-P2.54-LS10.3-TL; MPN PC817SC; LCSC Part C20612450
U5: MT2492; SOT-23-6_L2.9-W1.6-P0.95-LS2.8-BL_3; MPN MT2492; LCSC Part C89358

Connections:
+5V: C9.1, C11.1, J2.5, J2.6, L2.2, R1.1, R15.1
+12V: C1.1, C4.1, C10.1, D1.1 (K), J2.1, J2.2, R2.1, R7.1, R8.1, R17.1, U5.5 (IN)
/Aux: C3.1, D7.1 (K), D8.2 (A), J4.1
/Aux_CNTRL: C12.1, D8.1 (K), U1.5 (VDD)
/FB: C6.2, U1.8 (COMP), U4.4 (COL)
/VDCH: C5.1, C7.1, J1.1, R11.2, R20.2, U3.1
/VDCH_CND: J4.2, R22.1, R23.2
GND: C1.2, C4.2, C9.2, C10.2, C11.2, D4.1 (K), D5.1 (K), J2.3, J2.4, J2.7, J2.8, R9.2, R16.2, U2.3 (A), U3.6 (S1), U5.2 (GND)
GNDPWR: C3.2, C6.1, C7.2, C12.2, J1.2, J4.3, J4.4, R13.1, R23.1, U1.1 (GND), U1.2 (GND), U1.3 (N.C.), U1.4 (N.A.), U1.7 (FB), U3.4 (A1), U4.3 (EM)
unnamed: C2.1, R18.2
unnamed: D1.2 (A), U3.5 (S1)
unnamed: D3.1 (A), U1.13 (DRAIN), U1.14 (DRAIN), U1.15 (DRAIN), U1.16 (DRAIN), U3.2 (P1)
unnamed: C5.2, D3.2 (C), R10.1
unnamed: D4.2 (A), R1.2
unnamed: D5.2 (A), R2.2
unnamed: D7.2 (A), U3.3 (A1)
unnamed: R10.2, R19.1
unnamed: R11.1, R19.2
unnamed: R14.2, R16.1
unnamed: R20.1, R21.2
unnamed: R21.1, R22.2
unnamed: R13.2, U1.6 (LIM)
unnamed: C2.2, R12.2, U2.1 (K), U4.2 (CAT)
unnamed: R8.2, R9.1, R18.1, U2.2 (REF)
unnamed: R7.2, R12.1, U4.1 (AN)
unnamed: C8.2, U5.1 (BS)
unnamed: R17.2, U5.4 (EN)
unnamed: R14.1, R15.2, U5.3 (FB)
unnamed: C8.1, L2.1, U5.6 (SW)

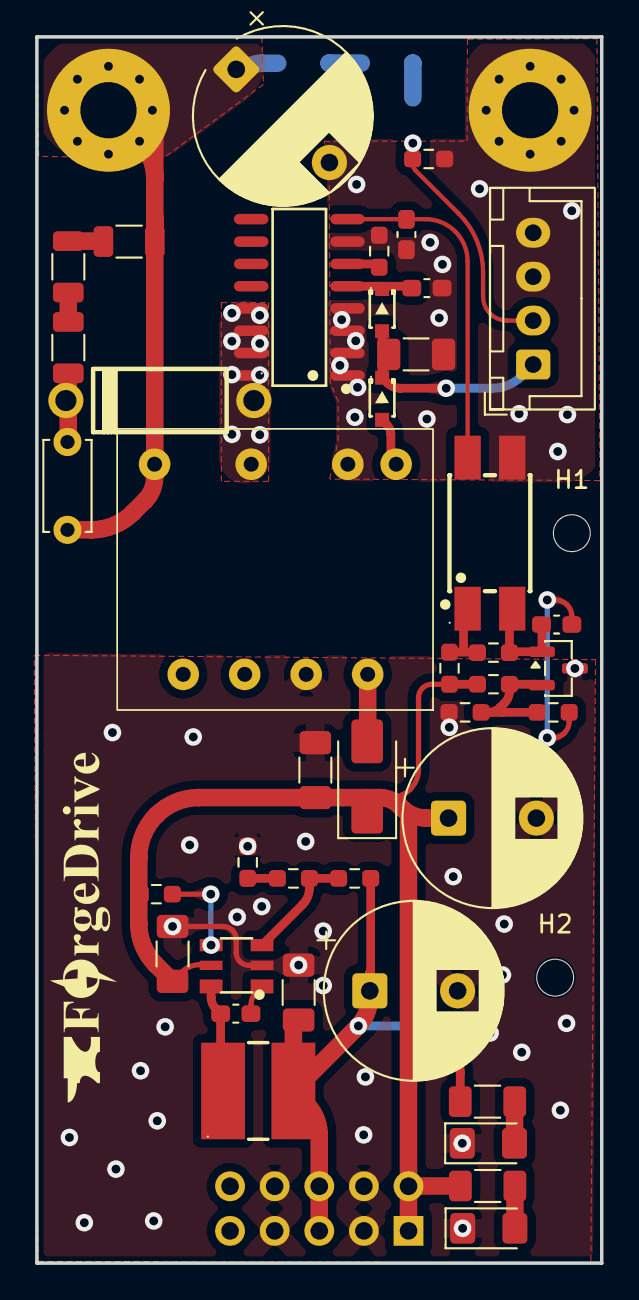
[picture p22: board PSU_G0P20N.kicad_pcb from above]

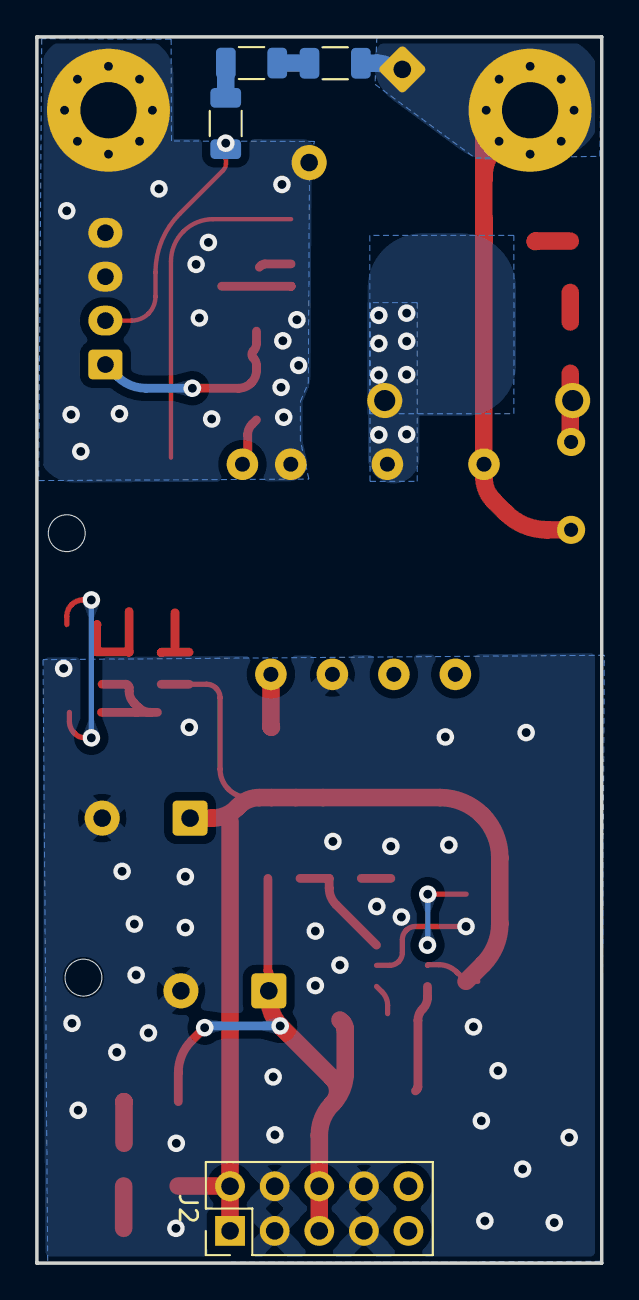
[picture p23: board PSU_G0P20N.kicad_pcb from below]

Board: 2 copper layers, 32.1 x 69.8 mm, 48 parts (4 on the bottom side), 29 nets.

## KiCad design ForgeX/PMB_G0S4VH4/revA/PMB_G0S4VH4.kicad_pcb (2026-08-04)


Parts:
C1, C2, C4: 450V, 150u; CP_Radial_D22.0mm_P10.00mm_SnapIn
H1, H2: MountingHole; MountingHole_5.3mm_M5_DIN965
J1, J2, J3, J12: Screw_Terminal_01x03; SPACER_M3_PCONN_2x03
J4, J5, J6, J8, J9, J13, J14, J17: Screw_Terminal_01x01; M3_PCONN_1x01
JP1, JP3, JP4, JP5: Jumper_2_Bridged; PowerJumper_PMB

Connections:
/Phase_{A}: J1.2, JP1.1 (A)
/Phase_{B}: J2.2, JP3.1 (A)
/Phase_{C}: J3.2, JP4.1 (A)
GND: C1.2, C2.2, C4.2, J1.3, J2.3, J3.3, J12.3, J13.1 (Pin_1_1), J14.1 (Pin_1_1)
HVDC: C1.1, C2.1, C4.1, J1.1, J2.1, J3.1, J8.1 (Pin_1_1), J9.1 (Pin_1_1), J12.1
unnamed: J4.1 (Pin_1_1), JP4.2 (B)
unnamed: J5.1 (Pin_1_1), JP3.2 (B)
unnamed: J6.1 (Pin_1_1), JP1.2 (B)
unnamed: J12.2, JP5.1 (A)
unnamed: J17.1 (Pin_1_1), JP5.2 (B)

Board: 2 copper layers, 21 parts (0 on the bottom side), 10 nets, no tracks yet.

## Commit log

2026-07-24 Project Init
    [HBM_U400P10.kicad_pcb, HBM_U400P10.kicad_sch, HBM_U400P10.step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]
2026-07-25 LVP_EcoDrive Done, Finalized
    [HBM_U400P10.kicad_pcb, LVP_EcoDrive.kicad_pcb, LVP_EcoDrive.kicad_sch]
2026-07-26 Added : Fused Inputs for LVP
    [LVP_EcoDrive.kicad_pcb, LVP_EcoDrive.kicad_sch]
2026-07-26 (LVP_Ecodrive) Added : Increase Pcb size by 3-4mm , much better grounding
    [LVP_EcoDrive.kicad_pcb]
2026-07-27 rearchitect the repository organisation
    [HBM_U400P10.kicad_pcb, HBM_U400P10.kicad_sch, HBM_U400P10.step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]
2026-07-28 psu_init and leg_inverter simulation added
    [HBM_U400P10.kicad_sch, PSU_U400O12n5.kicad_pcb, PSU_U400O12n5.kicad_sch]
2026-07-29 add bootstrap resistor on HBM mdoule
    [HBM_U400P10.kicad_pcb, HBM_U400P10.kicad_sch, PSU_U400O12n5.kicad_pcb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]
2026-07-29 hbm_U40010 sot-363 package updates
    , better handsoldering
    [HBM_U400P10.kicad_pcb, PSU_U400O12n5.kicad_pcb, PSU_U400O12n5.kicad_sch]
2026-08-01 Major redesign & Reworks
    * Star grounding scheme enforced across the whole ForgeX design....
    * Viper26 based PSU designed
    * Better signal integrity & decoupling on LVP and major reroute
    * Laminated DC bus (Biplanar) , instead of (Coplanar) , for heavily reduced bus inductance & equivelant Electrolytics ESL
    [HBM_U400P10.kicad_pcb, HBM_U400P10.kicad_sch, HBM_U400P10.step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]
2026-08-02 HBM quick change
    Swapped L6385ED MGD to L6388ED, since it is a better fit for the application
    [HBM_U400P10.kicad_pcb]
2026-08-04 Major reworks
    Major project reworks, Module renaming, Module rerouting, reinforced grounding scheme
    [HBM_G0VH4C5.kicad_pcb, HBM_G0VH4C5.kicad_sch, HBM_G0VH4C5.step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]
2026-08-06 BlackDev Fini & HBM mod
    Finalized blackDev, HBM with (RC) ground coupling, LVP swapping RS422 to RS485 and processing card interface modifications
    [BlackDev_G0Basic.kicad_pcb, BlackDev_G0Basic.kicad_sch, HBM_G0VH4C5.kicad_pcb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]
2026-08-06 G0 images added for doc
    [HBM_G0VH4C5.kicad_pcb]
